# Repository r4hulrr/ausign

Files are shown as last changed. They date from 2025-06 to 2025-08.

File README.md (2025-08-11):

# AUSIGN – Real-Time Auslan Sign Language Interpreter

 **Breaking communication barriers** for the Australian Deaf community with an affordable, wearable, real-time Auslan-to-speech translation glove. Check out the [demo video](https://drive.google.com/file/d/1WPN_qFuqe7VqrdAuftsNLOaqI1UlMCOe/view?usp=sharing).

## Overview
**AUSIGN** is a wearable assistive technology device designed to translate **Australian Sign Language (Auslan)** into spoken English **in real time**, enabling smoother and more natural communication for deaf and non-verbal individuals.

Unlike existing ASL-centric devices, AUSIGN is **purpose-built for Auslan**, incorporating contextual awareness via a heart-rate sensor, low-latency audio feedback, and Bluetooth connectivity for flexible output through a mobile/desktop app.

##  Key Features
- **Auslan-specific design** – recognises grammar and gestures unique to Auslan.
- **Context-aware translation** – heartbeat sensing to infer emotional tone.
- **Low-latency output** – low latency translation for natural conversations.
- **Comfort & portability** – under 150 g, designed for all-day wear.
- **Cross-platform UI** – BLE-connected Python GUI.
- **Rechargeable & all-day battery life** – ~6 hours continuous operation.

## System Architecture

**High Level Diagram**

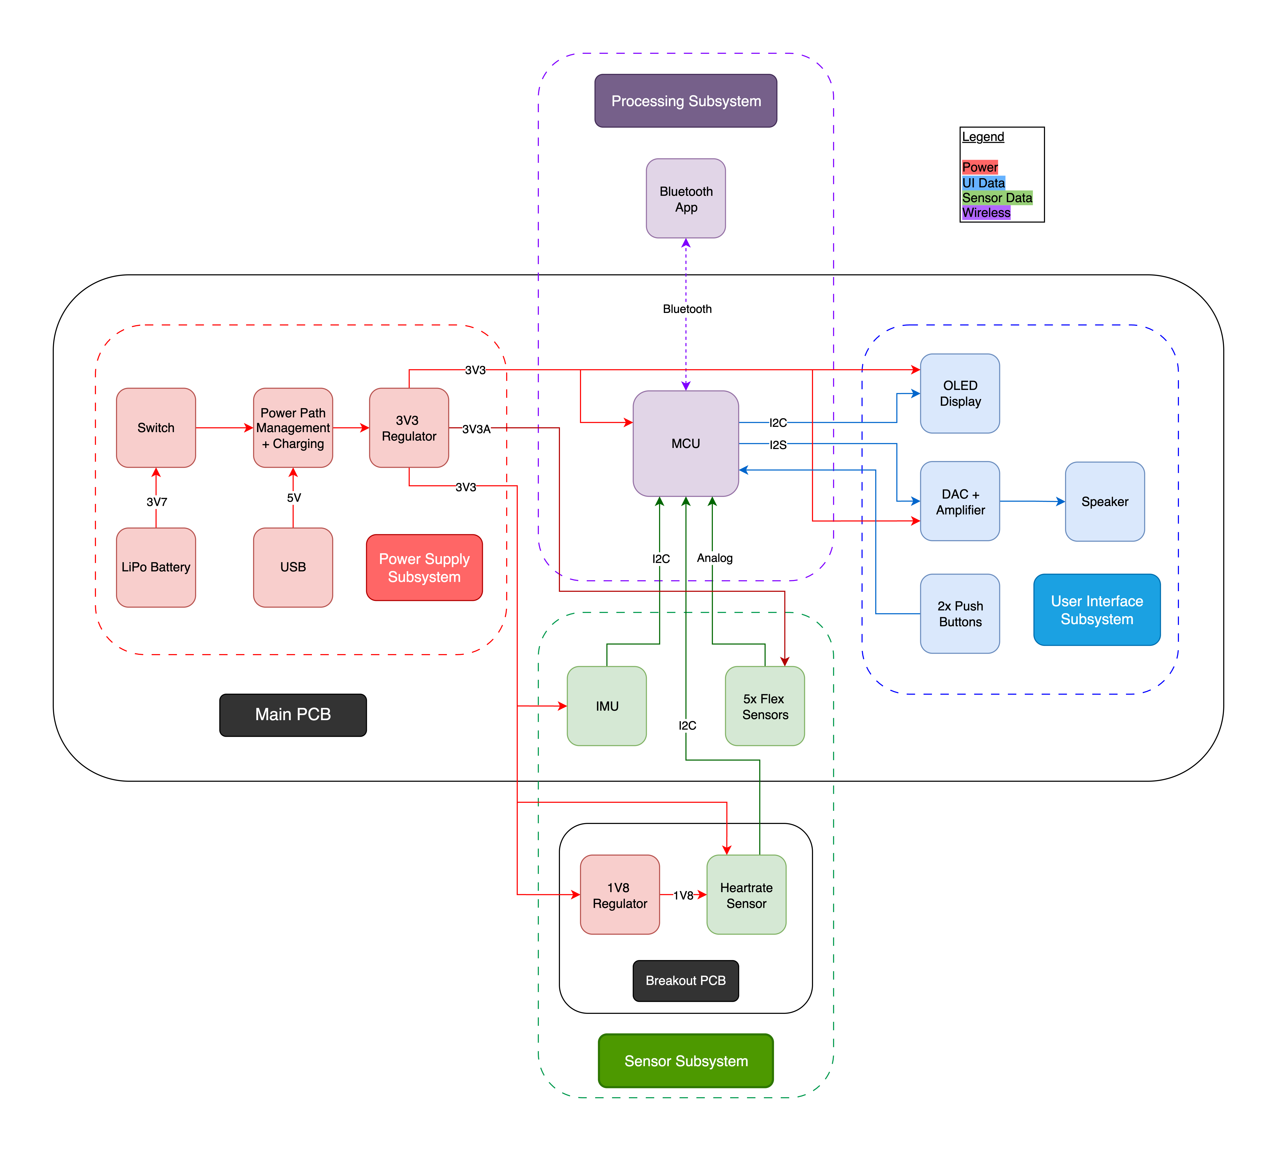
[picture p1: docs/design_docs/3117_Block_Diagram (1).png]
High Level Diagram


**Hardware**
- **Sensors:**  
  - 5× flex sensors for finger bend detection  
  - LSM6DSOTR 6-axis IMU for hand motion/orientation  
  - MAX30105 heartbeat sensor for emotional context  
- **Processing:** ESP32-S3 microcontroller with BLE & I²S audio output  
- **Output:** OLED display + speaker (via MAX98357A DAC/amp), 2× customisable push buttons  
- **Power:** 3.7 V Li-Po battery with BQ24074 power management & charging

**Software**
- **Firmware:** Reads sensor data, sends via BLE to host app, plays audio from internal flash.  
- **Recognition algorithm:** Condition-matching engine using flex, IMU, and BPM thresholds from CSV definitions.  
- **GUI:** Python-based BLE interface for displaying recognised signs, sensor status, and audio playback.  

## Repository Structure
```
├── firmware/ # ESP32-S3 C++ firmware (Arduino/ESP-IDF)
│ ├── src # Contains the main esp32 code along with test code for every component
│ ├── partitions # Custom partition implemented for our 16MB Flash size
├── gui/ # Python BLE GUI application
│ ├── frontend.py # main GUI script
│ ├── signs.csv # Sign definition mappings
│ └── ...
├── hardware/ # PCB schematics and board layouts
│ ├── main_board/
│ ├── breakout_board/
├── demo # Demo video
│ ├── demo_video.mp4
├── docs/ # design docs
└── LICENSE
└── README.md
```

## Demo
Check out the [demo video](demo/demo_video.mov) to see AUSIGN in action.

## License
This project is licensed under the [MIT License](LICENSE).

## Authors
- **Rahul Ramachandran** 
- **Enzo Moriguchi** 

---
> *“Technology is best when it brings people together.”* – AUSIGN aims to bridge the communication gap and foster inclusion through engineering innovation.

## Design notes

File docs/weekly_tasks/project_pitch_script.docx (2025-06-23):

Slide 2 – Introduction & Needs Assessment

The Problem
Deaf and non-verbal Australians often lack affordable, real-time ways to communicate without an interpreter. Auslan support in existing devices is nearly absent.

Limitations of Current Solutions

- Expensive (e.g. Brightsign glove ≈ $6,800 AUD)
- Mostly support ASL, not Auslan
- Require phones/internet, lack context awareness

User Needs

- Real-time Auslan-to-speech
- Portable, offline, affordable
- Emotion/context inference
- Intuitive, day-long use

🔷 Slide 3 – Market Analysis

User Validation (21 Respondents)

- 67% currently use aids
- Avg usefulness: 6.1/10
- Openness to new devices: 8.2/10
- 62% interested in AUSIGN

Market Opportunity

- 16,000 Auslan users (2021 Census)
- 3.6M Australians with hearing loss → 7.8M by 2060
- Interpreter costs ≈ $127.50/hr
- Existing solutions out of stock, ASL-only

Target: Auslan users aged 25–59 needing daily, affordable communication tools

🔷 Slide 4 – Key Requirements

- ≤ 50g per glove
- ≥ 12 hours battery life
- ≥ 90% translation accuracy
- ≤ 2 seconds latency
- Offline functionality
- Under $100 manufacturing cost
- Customizable settings (volume, dialect)
- Emergency signal support

🔷 Slide 5 – Product and Design Concepts

Product Concept
AUSIGN is a wearable glove that captures Auslan gestures and translates them to spoken English via onboard or phone-based audio.

Design Highlights

- Flex sensors + IMU = accurate gesture detection
- Heartbeat sensor = emotional context
- ESP32 = processing + Bluetooth for personalization
- Onboard speaker + optional LCD feedback
- Custom mapping of signs
- Emergency button (e.g., “Help”)

🔷 Slide 6 – Unique Selling Points

1. Auslan-specific – Not ASL-focused like competitors
2. Context-aware – Heart rate input for emotion detection
3. Gesture + Motion Fusion – Flex + IMU improves accuracy
4. Lightweight & Comfortable – Under 50g
5. Bluetooth-Enabled – Mobile app for personalization
6. Offline Support – Usable without internet
7. Custom Sign Training – Adaptable to regions/users
8. Affordable – Sub-$100 vs $6,800 competition

🔷 Slide 7 – High-Level Block Diagram

Use your Week 3 block diagramshowing:

Subsystems:

- Input: Flex sensors, IMU, Heartbeat, Button
- Processing: ESP32
- Output: Speaker, LCD
- Power: LiPo battery, TP4056, Boost Converter
- Communication: Bluetooth to App

Label clearly: arrows showing data flow, highlight modularity and context handling.

🔷 Slide 8 – Technical Components

Subsystem | Component | Notes
MCU | ESP32-WROOM-32 | I2C, UART, ADC, Bluetooth
Finger Sensor | 3” Flex Sensors | 25k–100kΩ resistance range
Motion Sensor | MPU6050 IMU | 6-axis detection
Biometric Sensor | MAX30102 | Heart rate & oximeter
Output | 3W Speaker, 20×4 LCD | Compact + intuitive UI
Power | TP4056 + LiPo + MT3608 | USB charging + 5V boost
Input | Tactile Push Button | Emergency signal

🔷 Slide 9 – Financial Plan

Per Unit Manufacturing Estimate

- ESP32: $8
- Flex Sensors ×5: $20
- MPU6050: $5
- MAX30102: $6
- Speaker + Amp: $4
- LCD: $7
- Power Circuit (TP4056 + MT3608): $3
- Misc (PCB, Glove Material, Button): $15 → Total: ~$68 AUD

Selling Price: $150–200 AUD
NPV: Viable pricing based on competitor comparison
Profit Margin: ≥ 100%, with accessibility focus

🔷 Slide 10 – Development Plan (Wk 6–10)

Week 6–7

- Hardware Integration (Flex + IMU + HR + Speaker)
- Sensor Calibration

Week 8

- Real-time Auslan-to-Speech Mapping
- Bluetooth App UI + Emergency Button Logic

Week 9

- Context Awareness Logic (Heart rate threshold)
- Output testing with user trials

Week 10

- Final Testing + Demo
- User Feedback + Iteration
- Presentation and Documentation

Team Allocation:

- Hardware: [Name]
- Firmware + ML Model: [Name]
- App + UI: [Name]
- Integration & Testing: All

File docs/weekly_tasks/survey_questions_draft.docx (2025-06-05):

# AUSIGN - An AUSLAN Interpreter

The primary concept behind AUSIGN is to design a pair of smart gloves that interpret Auslan (Australian Sign Language) and convert the signs into spoken language via built-in speakers. This will empower individuals who are deaf or nonverbal to communicate more easily with the broader public, particularly in situations where an interpreter is not available.

One of our key design goals is to make the gloves lightweight, portable, and comfortable, but we also understand that usability involves more than just hardware specs. To ensure that AUSIGN addresses real user needs, we are conducting primary market research through a structured survey. This will help us:

- Validate the real-world usefulness of our concept
- Gather direct feedback on desirable features, comfort, pricing, and expectations
- Understand attitudes within the Deaf and non-verbal community toward current assistive technologies

In order to gather meaningful and relevant insights, we plan to distribute this survey to individuals who are deaf, hard of hearing, or non-verbal, as well as people who work closely with them (e.g. Auslan interpreters, educators, and disability support workers). Specifically, we will target local Deaf advocacy and community groups along with online forums and Reddit communities (e.g. r/auslan, r/deaf).

Keeping this in mind, we came up with around 10 questions that we feel would help us best understand the market. We distributed them to the above mentioned groups through online forms to the best of our ability. We also got our relatives and anyone they knew who had a hearing impairment to fill out our form in order to get more data. In total, we received about 21 responses. The questions and the results are as follows:

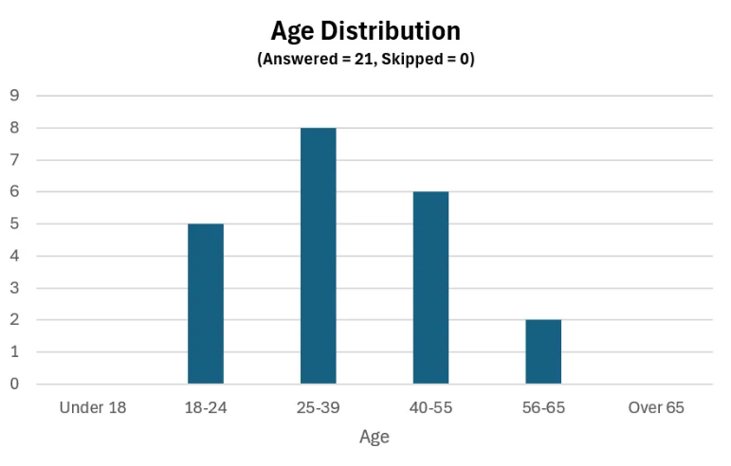
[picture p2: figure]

Section 1: Demographics

1. Age:
  a. Under 18
  b. 18 - 24
  c. 25 - 39
  d. 40 - 55
  e. 56 – 65
  f. Over 65
2. What is your level of hearing loss?

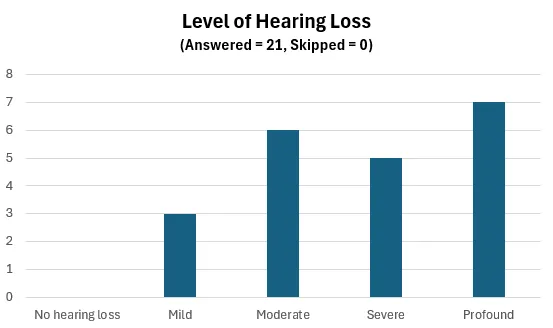
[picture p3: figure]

  a. No hearing loss
  b. Mild (21 - 40dB)
  c. Moderate (41 - 70dB)
  d. Severe (71 - 90dB)
  e. Profound (91+ dB)
3. Are you also non-verbal or do you experience speech difficulties?

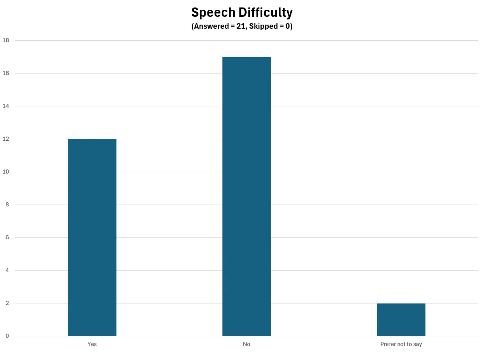
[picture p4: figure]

  a. Yes
  b. No
  c. Prefer not to say

Section 2: Communication Tools and Tech Usage

4. Do you currently use any assistive devices for communication?

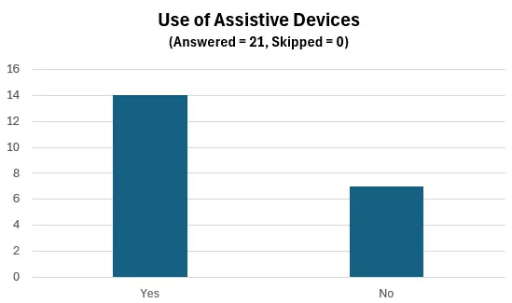
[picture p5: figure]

  a) Yes
  b) No
5. (If answered Yes above)

What communication device(s) do you currently use?

(Open-ended)

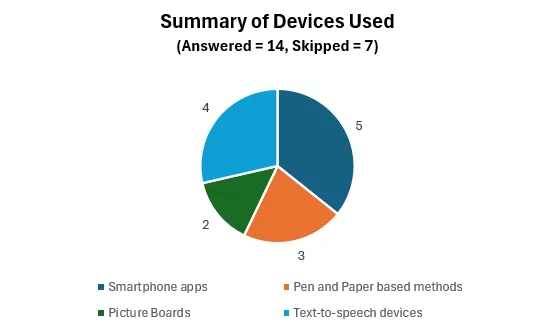
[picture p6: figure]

6. (If answered Yes above)

On a scale of 1 to 10, how useful is your current communication aid in daily life?

(1 = Not useful at all, 10 = Extremely useful)

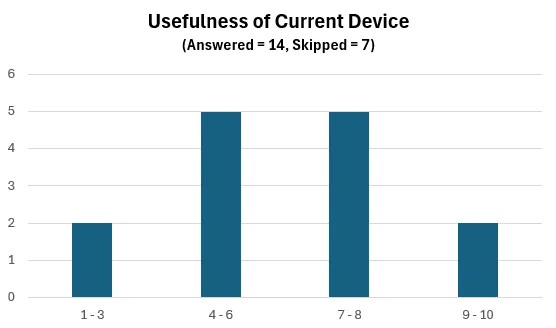
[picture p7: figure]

7. (If answered No to Q4)

How open are you to using a new device that may improve daily communication?

(1 = Not open at all, 10 = Very open)

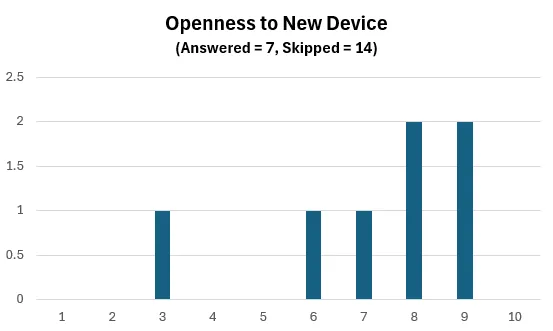
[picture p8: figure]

Section 3: Product-Specific Feedback

8. Would you be interested in using a device like AUSIGN that converts Auslan gestures to speech? If no, why?

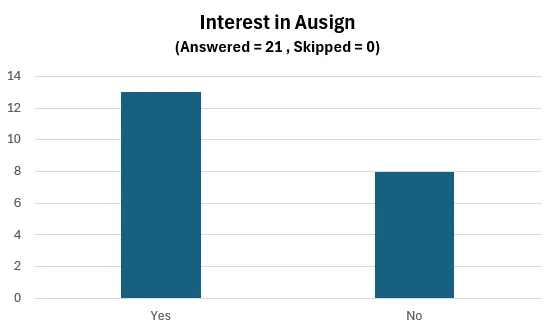
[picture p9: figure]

(Primary reasons for not interested deviate towards concerns about feasibility of complete interpretation of Auslan as it relies on facial expressions and context. There were also concerns about regional sign variation.)

9. Aside from translating sign language into speech, are there any additional features you believe would make this product more useful or appealing for members of the Deaf or non-verbal community?

(Most features fall under context awareness, ease of use, long battery file and comfortability)

10. What price range would you consider reasonable for this product?

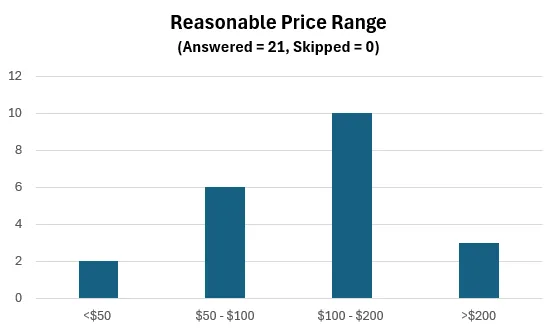
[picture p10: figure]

  a. Less than 50 AUD
  b. 50 to 100 AUD
  c. 100 to 200 AUD
  d. Over 200 AUD

Survey Outcomes

As mentioned before, our survey gathered input from 21 respondents within the Deaf and non-verbal community. Most were aged 25–55 with moderate to profound hearing loss, confirming a mature and tech-aware user base. Around 67% currently use communication aids—mostly smartphones or text-to-speech devices—with an average usefulness rating of 6.1/10, suggesting scope for improvement. Non-users reported a high openness to trying new tools (average 8.2/10), validating demand for improved solutions.

62% expressed interest in AUSIGN, but 38% raised concerns based on past devices that failed to capture Auslan’s full complexity (e.g. facial cues, grammar, regional signs). Using ML to achieve context awareness and having a larger data set could help with this issue as it seemed to be a major point of concern among many. Most respondents supported a $100–200 AUD price range. These findings will guide AUSIGN’s design focus on usability, adaptability, and affordability.

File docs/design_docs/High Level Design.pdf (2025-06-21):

# AUSIGN - An AUSLAN Interpreter

### Product Functions (Summary List)

1. Detect finger bending positions (sign gestures)
2. Detect hand orientation and motion (gesture context)
3. Detect emergency signals via a panic button
4. Measure heart rate for emotional context
5. Convert gestures into audio messages
6. Display information to the user (feedback)
7. Transmit sensor data wirelessly to a host system (e.g., smartphone)
8. Provide power to the entire glove system

# High-Level Block Diagram

AUSIGN | - An AUSLAN Interpreter | 1

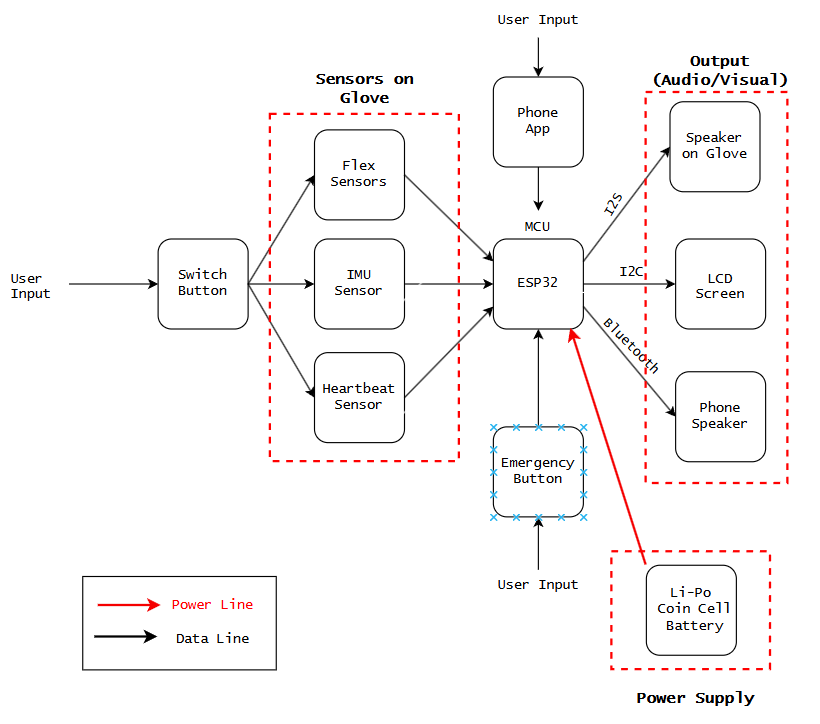
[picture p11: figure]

# Technical Components

### 1. Microcontroller Unit – ESP32-WROOM-32

Manufacturer: Espressif Systems

Justification:

Integrated Bluetooth and Wi-Fi for communication
Rich peripheral set (ADC, I2C, UART, PWM) enables interfacing all sensors without external chips

3.3V operation matches sensor logic levels
Dev board form factor suitable for breadboarding and prototyping

Extensive community support and low cost

### 2. Flex Sensors – 3" 25kΩ-100kΩ variable resistance

Manufacturer: Adafruit

Justification:

Widely used, robust component specifically designed for detecting single-axis bending, perfect for finger gesture recognition.
Resistance changes from ~25kΩ (flat) to ~100kΩ (fully bent), easily measurable using a voltage divider circuit with ESP32's ADC.

Readily available

### 3. IMU Sensor – MPU6050

Justification:

Integrates 3-axis accelerometer and gyroscope
I2C interface supported directly by ESP32

Compact and well-documented, with sample code and libraries Low power consumption, ideal for wearables

### 4. Heartbeat Sensor – MAX30102

Manufacturer: TZT
Justification:

Optical pulse oximeter and heart-rate sensor in one package Integrated LED driver and ADC simplifies design

I2C communication and low power use align well with ESP32

### 5. Speaker – Mini Speaker 3W, 4Ω, 4cm diameter

Manufacturer: YTDMEN

Justification:
Compact and lightweight for glove mounting

Suitable for low-power PWM/I2S audio output from ESP32 Easily driven with audio amplifier if needed

### 6. Emergency Push Button - Mini Push Button Switch

Manufacturer: Sparkfun

Justification:

Simple digital input to MCU with internal pull-up/down Small tactile form factor suitable for glove

### 7. LCD Display – Freenove I2C 20x4 LCD Module

Manufacturer: Freenove

Justification:

Low power I2C interface with ESP32
Provides clear user feedback in compact form

Widely supported libraries for display text and icons Reasonably priced and readily available

### 8. Power Module – TP4056 + 3.7V LiPo Battery + Boost Converter (MT3608)

Justification:
TP4056 for USB charging and battery protection

LiPo battery offers lightweight portable power
MT3608 boost converter supplies stable 5V to speaker and peripherals as needed

Cost-effective and widely available modules

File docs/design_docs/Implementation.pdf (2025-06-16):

# Implementation

The first part to implement will be the flex sensors. These are essentially variable resistors (like potentiometers). As seen in the datasheet below, the resistance varies between 5 kΩ and 10 kΩ. I will connect the flex sensor in series with a
3.3 kΩ resistor to 3.3 V (VCC), and use the midpoint between the two resistors as the input to the ADC.
This forms a basic voltage divider. Theoretically:
Minimum ADC voltage (when flex = | 10 kΩ):
Maximum ADC voltage (when flex = | 5 kΩ):Vout=5+105×3.3=1.1 V

So the voltage range at the ADC will be 1.98 V to 2.48 V, depending on the bend angle.

Vout = 10+3.3 ×

10 3.3 = 2.48V

Vout = 5+3.3 ×

5 | 3.3 = 1.98V

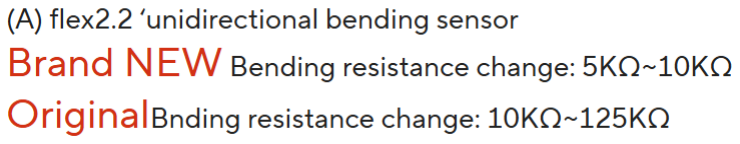
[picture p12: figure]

Implementation | 1

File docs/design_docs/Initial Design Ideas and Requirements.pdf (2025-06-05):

# AUSIGN - An AUSLAN Interpreter

# Needs Assessment

Who are you designing the product for? What is your target audience? People who have hearing and/or speech impairment, and use sign language to communicate. Targeting the Australian community specifically.

Why do they need it?
From our market research, we can see that a good percentage of Australians with hearing and/or speech impairment feel ostracized from society due to not being able to properly communicate with the wider public. There is a lot more research/projects targeting ASL (American Sign Language) but very little for AUSIGN, leaving them in the dust.

What do they need?
Again looking at our primary and secondary market research, there is a lack of a sure front and easy way for our target audience to communicate with the larger public. A lot of them use smartphone apps/ text-to-speech devices but are not satisfied with the current scope of technology available to them. They are skeptical of previous products as they do not take into account the context issues associated with it. E.g. The word for “chair” could mean “sit” depending on context. They also prioritize portability and ease of use.

Where and how will it used?
Ideally, we would like to incorporate a device with extended battery life, allowing our target audience to use the device throughout the day, as this product would be of the utmost importance during emergencies, which we cannot predict. It will
AUSIGN | - An AUSLAN Interpreter | 1

be available as easy to wear gloves and will convert their hand movements into audio through a speaker attached on the glove.

What features do they need in it?

Long battery life
Portable and lightweight

Ease of use with a easy to access button to turn on/off the gloves
Strong and solid UI to adjust the gloves based on personal preferences (e.g. volume, special signals etc)

Large database of signs with context awareness

What are the issues/limitations of existing products/solutions?
As mentioned before, most devices are based on ASL with little to no support for AUSLAN. They also lack context awareness which severely limit the usage of these devices as it could be very different to traditional sign language. Also fail to recognize facial expressions as they affect what the sign could mean (e.g. signs with a tensed look on face could be associated with more strong meanings which the products in the market fail to identify)

# Requirements Analysis

Lightweight - This is a strong requirement among most of our respondents. Light cotton gloves weigh around 15-30 grams per glove; winter-fleeced gloves weigh around 40-60 grams per glove and mechanics/work gloves can weigh up to 100 grams per glove. We want our users to be comfortable so would want to keep our gloves weight to around 50 grams per glove.

Long battery life - Another strong requirement. Should last at least a full day of charge.
Durable - Would not want to keep replacing gloves

High accuracy - Would want it to be highly accurate with a large database of signs with context awareness

# Problem Statement

Deaf and non-verbal individuals in Australia need an effective, real-time communication tool because current solutions—such as text-to-speech apps and sign language gloves—fail to interpret the full complexity of Auslan, often lacking contextual awareness, facial expression recognition, and support for regional variation. This communication barrier limits independence and inclusivity in everyday social, professional, and emergency situations.

# Product Concept

AUSIGN is a wearable communication aid designed to empower deaf and non-verbal individuals by translating Auslan (Australian Sign Language) gestures into spoken language. It aims to reduce communication barriers in everyday settings such as public transport, workplaces, retail, and healthcare. By doing so, it helps users engage more independently with the broader community without needing an interpreter present.
The product is intended to be lightweight, comfortable, and easy to use throughout the day. It will support user-specific preferences and context-aware communication to make interactions feel more natural and intuitive. AUSIGN directly addresses the unmet needs identified through our user research, especially around portability, reliability, and the lack of Auslan-specific solutions in existing products.

# Design Concept

AUSIGN will consist of pair of light gloves with flex sensors along the fingers to detect stretching/folding of fingers. An Inertial Measurement Unit will be placed along the wrist. This combines an accelerometer (to measure linear motion), gyroscope (to measure rotational motion) and potentially a magnetometer (to measure orientation). These two can be combined to help us understand the hand movements made by the user in sufficient detail. The values from this sensor will be fed into an ESP32, which will process these signals and drive the audio output on the speaker attached to the glove.
To enhance context-awareness, a heartbeat sensor will be incorporated into the glove system. By monitoring the user’s physiological state (e.g. elevated heart rate during stress), the device can infer emotional tone or urgency behind signs. This serves as a partial substitute for facial expressions and body language, which are key components of Auslan communication but difficult to capture with sensors alone.
An ESP32 is chosen as it has Bluetooth capabilities which would allow us to make a frontend app to enhance user experience and modify certain settings such as voice output volume, gesture sensitivity, preferred Auslan dialect, and custom sign mappings to their particular needs.
We will use a 3.7V 800mAh Li-Po battery as this is lightweight, rechargeable with a good energy density allowing for a long battery life. An easy to use button should also be included to turn on/off the gloves and also for emergency situations(e.g. to shout ‘help’ in case of emergency - this would be user customizable).

# Unique Selling Points

1. First Auslan-Focused Wearable Translator
Unlike most sign-to-speech devices built for American Sign Language (ASL), AUSIGN is designed specifically for Auslan, addressing regional sign variations and grammar unique to the Australian Deaf community.
2. Context-Aware Translation Using Biometrics
AUSIGN uses a heartbeat sensor to infer emotional tone (e.g. urgency or stress), adding contextual awareness that conventional gloves lack.
3. Gesture + Motion Fusion for High Accuracy
Combines flex sensors on fingers with a wrist-mounted IMU (inertial measurement unit) to recognize both static hand shapes and dynamic gestures, improving recognition accuracy for complex Auslan signs.
4. Lightweight and Comfortable Design

Designed to weigh under 50g per glove, AUSIGN prioritizes long-term comfort for daily use, exceeding the wearability of most commercial smart gloves.

5. Bluetooth-Enabled Personalization App
Built on the ESP32, AUSIGN supports wireless communication with a companion mobile app, allowing users to adjust settings like voice output, gesture sensitivity, and dialect preference.
6. Custom Sign Mapping and User Training
Allows users to add personal or region-specific signs and train the system to recognize them, increasing inclusivity for diverse signers.
7. All-Day Battery Life with USB Charging
Powered by a 3.7V Li-Po battery optimized for energy-efficient use, the gloves can run for a full day and recharge via standard USB.
8. Voice Output Through Onboard or Phone Speaker
Offers both onboard audio output and phone-based speech relay, giving users flexibility based on environment and preference.

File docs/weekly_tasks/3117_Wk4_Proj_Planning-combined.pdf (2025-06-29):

# Week 4 Project Planning Task

## Task 1: Initial Estimate of Manufacturing Costs

Category | Item | Part Number | Source | Unit Price (AUD) | Quantity | Total Cost (AUD)
Components | MCU | ESP32-WROOM-32E | DigiKey | $7.75 | 1 | $7.75
| Battery | 3.7V LiPo Battery | Amazon | $27.00 | 1 | $27.00
| BMS | BQ24075 | DigiKey | $3.43 | 1 | $3.43
| IMU | LSM6DSOTR | DigiKey | $6.12 | 1 | $6.12
| Flex Sensors | FS-L-0055-253-ST | DigiKey | $12.73 | 5 | $63.65
| Heartbeat Sensor | MAX30207CLB +T | DigiKey | $5.69 | 1 | $5.69
| LCD Screen | MD21605G12W 3-BNMLW-VE | DigiKey | $7.34 | 1 | $7.34
| Speaker | K 23 - 8 OHM | DigiKey | $7.54 | 1 | $7.54
| Push Buttons | EVQ-P7C01P | DigiKey | $0.48 | 2 | $0.96
| Wires | - | DigiKey | ~0.20 | ~10 | ~$2.00
| Passives (Resistors & Capacitors) | - | DigiKey | ~$0.15 | ~30 | ~$4.50
| Gloves | Safe Work Gloves | Amazon | $5.00 | 2 | $10.00
Shipping | DigiKey | - | DigiKey | - | 1 | -
| Amazon | - | Amazon | - | 1 | -
| JLCPCB | - | JLCPCB | $27.51 | 1 | $27.51
Manufacturing | PCB | - | JLCPCB | $3.06 | 1 | $3.06
| Labour | - | - | $47.70/hour | 160 | $ 7632
| Equipment | - | - | $100 | 1 | $100
| Marketing | - | - | $100 | 1 | $100
| Overheads | - | - | $50 | 1 | $50
Total | - | - | - | - | - | $8052.05

### Shipping: - Amazon offers free shipping - DigiKey offers free shipping for orders > $100 AUD which is the case here

### Manufacturing: - PCB cost is for 5x PCBs as per minimum order requirements on JLCPCB - Labour hourly rate is based on average hourly wages for a Junior Engineer, according

### to Indeed. The number of hours is based on an estimate of 2x people working for 8x

hours per week for 10 weeks.

### - Equipment, Marketing and Overheads costs are all estimates

### Estimate of Potential Profitability

Discount Factor P/A | 10%
Year | 0 | 1 | 2 | 3 | 4
Cost | 8052.05 | 7500 | 7500 | 7500 | 7500
Revenue | 0 | 50000 | 60000 | 70000 | 80000
Future Value | | 42500 | 52500 | 62500 | 72500
Present value | -8052.05 | 38636.36 | 43388.43 | 46957.18 | 49518.48
NPV | 170448.39

## Task 2: Work Breakdown Structure

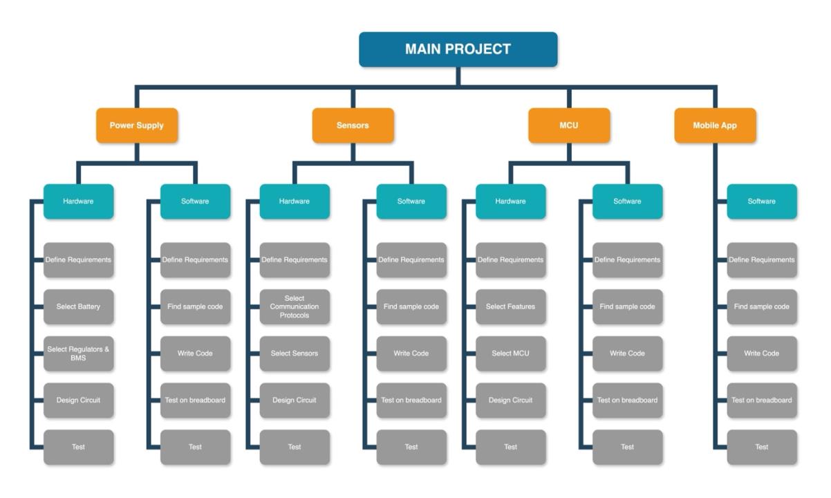
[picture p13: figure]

### Figure 1: Work Breakdown Structure

## Task 3: Gantt Chart

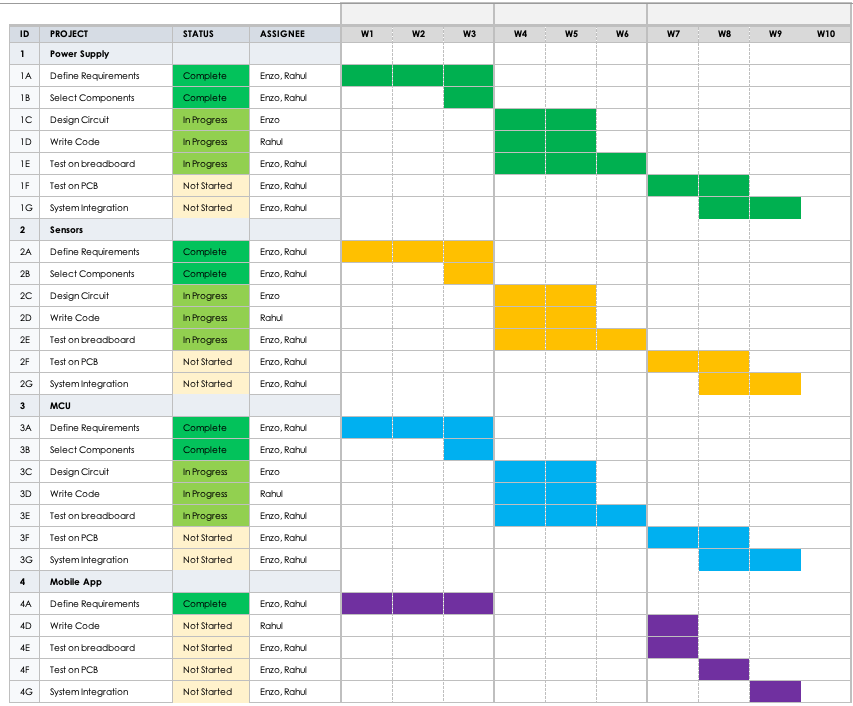
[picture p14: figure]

### Figure 2: Gantt Chart

## Task 4: Risk Assessment

Risk | Likelihood Impact | of Risk | Severity | Mitigation Strategy | Contingency Action
Sensor Signal Noise | Medium | High | High | Use low-pass filters and shielded cables; isolate analog and digital signals on PCB layout. | Re-route signal traces and add hardware filters. Use digital filtering fallback.
Poor Gesture Recognition Accuracy | High | High | High | Test with diverse gesture datasets; apply ML techniques or adaptive thresholds. | Retrain system with simplified gesture sets or manual tuning for reliable accuracy.
Microcontroller Memory Overflow | Low | Medium | Medium | Optimize firmware to store only essential variables; use memory-efficient data types. | Trim features in firmware or upgrade to MCU with higher memory if feasible.
Loose Wiring or Faulty Connections | Medium | High | High | Secure solder joints; use locking connectors and strain relief mechanisms. | Rewire or re-solder faulty joints. Replace cables/connectors and reverify.
Risk | Likelihood Impact | of Risk | Severity | Mitigation Strategy | Contingency Action
Low Market Adoption | Low | Medium | Medium | Engage with Auslan community early for feedback; showcase use cases to drive interest. | Pivot design for educational use or accessibility demos. Explore university partnerships.
Risk | Likelihood Impact | of Risk | Severity | Mitigation Strategy | Contingency Action
Missed Deadlines | Medium | High | High | Use a detailed Gantt chart; assign task owners and track weekly progress with buffer periods. | Rescope project: deprioritize low-impact features. Use weekend/makeup sprint.
Team Communication Gaps | Medium | Medium | Medium | Set weekly standups and shared task boards; ensure everyone is aligned. | Escalate blockers early. Allocate a group lead to facilitate communication.
Risk | Likelihood Impact | of Risk | Severity | Mitigation Strategy | Contingency Action
| High | Medium | Low
Battery Short Circuit or Overheating | Low | High | Medium | Add thermal cutoff and fuse. Use tested commercial battery pack with protection circuit. | Shut off glove immediately; switch to USB power for further debugging.

Technical

Business

Project Management

Safety

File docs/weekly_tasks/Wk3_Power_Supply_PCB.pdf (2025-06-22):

## Power Supply Design Assignment

Requirements

Parameter | Value
Input Voltage | 12V
Output Voltage | 3.3V
Output Current (max) | 500mA
Allowed Ripple | <100mV
Transient voltage deviation | +/-150mV
PCB Dimensions | 48mm x 48mm
I/O Connector | 2.54mm pitch header pins
Regulator IC: MC34063ECN
This regulator was chosen from the available options due to its THT nature for ease of soldering and is a very common component that has been widely used. Parameters such as max switch current and input voltage range were largely identical across the options and thus, did not influence the selection.
Calculations & Component Justification
The following calculations are primarily based on the equations provided in the MC34603ECN datasheet.
Feeback Resistors:
V_out = 1.25*(1+R2/R1) = 3.3V
R2 = 16.2kohm
R1 = 10kohm
V_out = 3.275V
These resistor values are standard values which give an output voltage that is within reason to the desired output voltage.
f = 50kHz, T = 1/f = 20us
A switching frequency of 50kHz was chosen as the maximum frequency of the IC is 100kHz and this value is within the safe operating range. This value also provides a good balance between minimising output ripple and avoiding greater switching losses.
Duty Cycle: D = 3.3V/12V = 0.275
t_on = D*T = 5.5us
t_off = (1-D)*T = 14.5us
Timing capacitor: C_T = 4.5*10^-5*t_on = 247.5pF = ~240pF
The value of 240pF as this is a standard value and is reasonably close to the calculated value such that it won’t affect the switching frequency of the IC.

I_PK(switch) = 2*I_out(max) = 2*500mA = 1A
R_SC = 0.3/ I_PK(switch) = 0.3/1 = 0.3ohm
Output capacitor: C_out = (I_PK(switch)*T)/(8*V_ripple) = (1*20u)/(8*100m) = 25uF =~22uF
This output capacitor value was chosen as it is a standard value and close to the calculated value.
Inductor (min): L_min = (V_in(min) – V_sat – V_out)/I_PK(switch)*t_on = (12-1.3-3.3)/1*5.5*10^-6 = 40.7uH = ~220uH
The equation provides the minimum inductor value which is required for the peak current to not exceed its requirement. However, a larger inductor provides a safe margin, reduces the output voltage ripple and improves performance during transients on the load. Thus, although the 82uH inductor may be adequate, the 220uH is more suitable and thus, was selected. Furthermore, the THT component of the inductor was selected due to the ease of soldering and changing out to the 82uH inductor if necessary or to compare their effects.

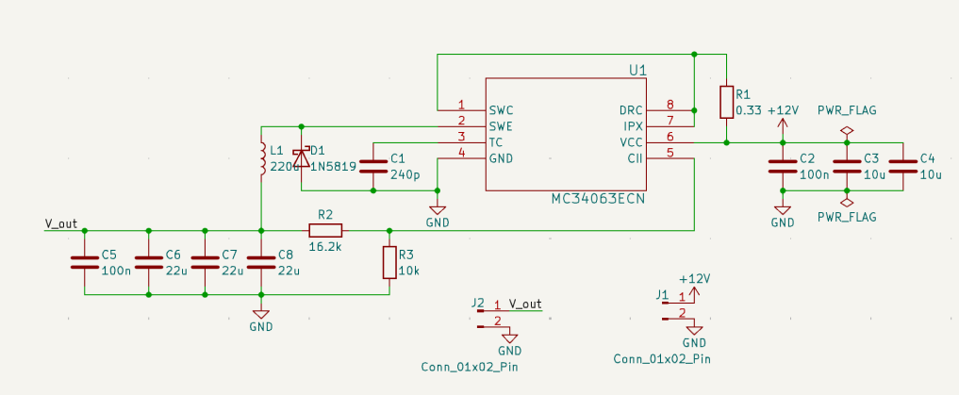
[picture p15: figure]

Figure 1: Schematic
Figure 1 above displays the schematic of the power supply design. It features all the components calculated earlier. The 1N5819 Schottky diode was chosen due to its low forward voltage drop, rating for 1A continuous and fast switching. This diode provides the discharge path for the inductor during the ‘OFF’ switching phase.
Input capacitor values of 100nF and 10uF were selected as the 100nF filters high frequency noise and the 10uF acts as a bulk energy storage. The output capacitor values of 100nF and 22uF were selected as the 100nF also filters out the switching and high frequency noise and the 22uF is from the calculations and is to supress the inductor output ripple. The schematic also features excess input and output capacitors which only the footprints will be placed to allow for optimisation during testing and provide no downside to the function of the design. These can be used to improve the output voltage ripple by increasing capacitance and reducing the equivalent series resistance (ESR), if needed.
All resistors and capacitors were chosen to be SMD, 0805 values with all capacitors being ceramic. The 0805 size was chosen as this is a common value that is large enough to hand solder if needed, particularly if capacitors need to be added or removed during testing. Furthermore, having all 0805 components allows for compatibility across different capacitor values.
Layout Justification

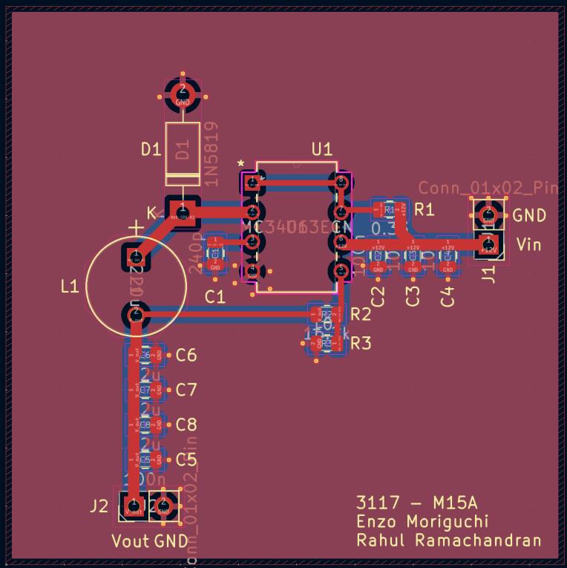
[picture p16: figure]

Figure 2: Layout
Figure 2 above displays the layout of the power supply, which features a 2-layer board with ground planes on both sides, stitched with vias close to all GND pads to provide low impedance return paths. All traces are kept short and direct, with 1mm width traces used for power traces to handle the higher currents and reduce resistive losses. 0.5mm traces were used for all other traces as they carry much less current.
On the input side, the 100nF input capacitor is placed closest to the IC to filter high frequencies with the larger 10uF capacitors placed close by for stabilising the input voltage. Similarly, the output capacitors are placed as close as possible to the output to filter out noise and smooth the voltage. The capacitors are placed slightly apart, not as close as possible, to allow for ease of modifications during testing as previously mentioned. This will allow for soldering or desoldering of single capacitors without affecting nearby capacitors.
The inductor and diodes are placed close to the output pin of the IC to minimise the loop area that can be formed from these components in conjunction with the output capacitors.
It should also be noted that although it is common practice to avoid 90-degree traces, the ones used here through the THT pins have little to no impact on the performance of the power supply, only to simplify routing, and given that this is not a high-speed design, with a low frequency (50kHz) used.

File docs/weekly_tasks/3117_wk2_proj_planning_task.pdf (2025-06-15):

# AUSIGN - An AUSLAN Interpreter

## Needs Assessment

Who are you designing the product for? What is your target audience?
We are designing this product predominantly for people who have hearing and/or speech impairment and use sign language to communicate. Of the many people around the world who use sign language, our target audience is the Australian community who use Auslan, the Australian sign language.
Why do they need it?
Our target audience of Auslan users need our product due to the lack of availability and accessibility of existing solutions. From our market research, we found that a good percentage of Australians with hearing and/or speech impairment feel ostracized from society due to not being able to properly communicate with the wider public. There is significant research and projects targeting ASL, the American Sign Language, but very little for Auslan, leaving them in the dust. Furthermore, our product will provide a simple solution that allows users to maintain their independence and reduce costs, compared to the current primary solution of a dedicated Auslan interpreter. This will be particularly beneficial in situations such as emergencies, workplace, school and university, doctors, and social events.
What do they need?
The target audience needs a solution that is portable and easy to use with a low cost, a lot of Auslan users don’t have the luxury of affording an interpreter. Looking at our primary and secondary market research, there is a lack of a sure front and easy way for our target audience to communicate with the larger public. A lot of them use smartphone apps or text-to-speech devices but are not satisfied with the current scope of technology available to them. They are sceptical of previous products as they do not consider the context issues associated with it. E.g. The word for “chair” could mean “sit” depending on the context. They need a product that can reliably translate Auslan to spoken English in real time. The product needs to have a long battery life, with the ability to charge, as needs to last a whole day of use and be intuitive.
Where and how will it be used?
The product will be used anytime and anywhere, when the user is at home, or leaves their home, i.e. workplace, school, university, doctors, social hangouts, restaurants, etc. Any setting where the user needs to communicate Auslan to spoken English, this product can be used. It will be available as an easy to wear gloves and will convert their hand movements into audio through a speaker attached on the glove.
What features do they need in it?
Features that are required for this product include:
- Long battery life: for lasting all day and in case of emergencies which can occur at any time.
- Portable and lightweight: for ease of use and portability
- Simple user interface: easy to access button to turn on/off the gloves
- Customisable settings: for adjusting the gloves based on personal preferences (e.g. volume, special signals etc)
- Large database of signs with context awareness: to differentiate between two words based on context
- Offline functionality: for use without the need for network coverage
- Comfort and durability: for user satisfaction and product longevity
What are the issues/limitations of existing products/solutions?
As mentioned before, most devices are based on ASL with little to no support for Auslan. They also lack context awareness which severely limit the usage of these devices as it could be very different to traditional sign language. Also, existing solutions fail to recognize facial expressions as they affect what the sign could mean (e.g. signs with a tensed look on face could be associated with more strong meanings which the products in the market fail to identify). Cost is another factor as existing glove-based products are very expensive and typically sold out, making them very inaccessible.

## Requirements Analysis

Lightweight – Each glove must weigh no more than 50 grams
- This is a strong requirement among most of our respondents from the survey. Light cotton gloves weigh around 15-30 grams per glove; winter-fleeced gloves weigh around 40-60 grams per glove and mechanics/work gloves can weigh up to 100 grams per glove. We want our users to be comfortable so would want to keep our gloves weight to around 50 grams per glove.
Long battery life – System must function for a minimum of 12 hours of continuous use on a single charge
- Another strong requirement desired by respondents through the survey. They expect a reliable product for constant use throughout the day and in emergency situations which could occur at any given time, where charging might not be possible.

Durable – Each glove must withstand a minimum of 6 months of regular daily use without degrading.
- Survey respondents highlighted the need for a reliable and low-cost solution. Many users, particularly those with lower incomes won’t be able to afford to replace or repair the product frequently.
High accuracy – The product must correctly translate Auslan to spoken English with 90% accuracy
- Incorrect translations could lead to miscommunication. This would be critical in emergencies where users may need to quickly and accurately communication their situation to get the correct help they need. Survey respondents also highlighted that inaccuracies in existing solutions cause frustrations.
Low latency – The output speech must be within 2 seconds of the sign gesture completion
- A delay between the sign gesture and output audio can undermine natural conversation. It can also lead to confusion in the listener, particularly if the user is constantly gesturing signs.
Customisable – The product must allow to user to adjust output volume and speed, and conserve battery life
- Depending on the situation and environment, the user may need to be louder or quieter. A method to turn on or off the product is necessary to preserve battery life.
Offline functionality – The product must operate without network coverage
- Users may need to use the product where they don’t have access to internet or cannot afford constant internet access.
Cost effective – The product must cost under $100 AUD to manufacture
- Existing solutions are very expensive and those particularly with a low income, can’t access sufficient solutions. Survey respondents also expressed their need for a low-cost solution as they aren’t willing to spend over $200 at most.

## Problem Statement

Deaf and non-verbal people in Australia need an effective, real-time communication tool to translate Auslan to spoken English. Current solutions, such as text-to-speech apps and sign language gloves, fail to interpret the full complexity of Auslan, often lacking contextual awareness and facial expression recognition. Other solutions such as an interpreter are very costly and hard to obtain. This communication barrier limits independence and inclusivity in everyday social, professional, and emergency situations.

## Product Concept

AUSIGN is a wearable communication aid designed to empower deaf and nonverbal individuals by translating Auslan (Australian Sign Language) gestures into spoken English. It aims to reduce communication barriers in everyday settings such as public transport, workplaces, retail, and healthcare. By doing so, it helps users gain more independence within the broader community without needing an interpreter present. The product is intended to be lightweight, comfortable, and easy to use throughout the day. It will support user-specific preferences and context-aware communication to make interactions feel more natural and intuitive. AUSIGN directly addresses the unmet needs identified through our user research, especially around portability, reliability, and the lack of Auslan-specific solutions in existing products.

## Design Concept

AUSIGN will consist of pair of lightweight, durable gloves with flex sensors along the fingers to detect stretching or folding of fingers. An Inertial Measurement Unit (IMU) will be placed along the wrist. This combines an accelerometer (to measure linear motion), gyroscope (to measure rotational motion) and potentially a magnetometer (to measure orientation). These can be combined to help us understand the Auslan hand movements made by the user in sufficient detail. The values from these sensors will be fed into an ESP32 microcontroller, which will process these signals and convert them to spoken English to drive the audio output on the speaker attached to the glove.
To enhance context-awareness, a heartbeat sensor will be incorporated into the glove system. By monitoring the user’s physiological state (e.g. elevated heart rate during stress), the device can infer emotional tone or urgency behind signs. This serves as a partial substitute for facial expressions and body language, which are key components of Auslan communication but difficult to capture with sensors alone.
The ESP32 was chosen as it has Bluetooth capabilities which would allow us to make a frontend app to enhance user experience and modify certain settings such as voice output volume, gesture sensitivity, preferred Auslan dialect, and custom sign mappings to their needs.
We will use a 3.7V 800mAh Li-Po battery as this is lightweight, rechargeable with a good energy density allowing for a long battery life. An easy-to-use button will also be included to turn on/off the gloves and for emergency situations (e.g. to shout “help” in case of emergency, this would be user customizable).

## Unique Selling Points

1. First Auslan-focused wearable translator. Unlike most sign-to-speech devices built for American Sign Language (ASL), AUSIGN is designed specifically for Auslan, addressing regional sign variations and grammar, unique to the Australian Deaf community.
2. Context-aware translation using biometrics. AUSIGN uses a heartbeat sensor to infer emotional tone (e.g. urgency or stress), adding contextual awareness that conventional gloves lack.
3. Gesture + motion fusion for high accuracy. Combines flex sensors on fingers with a wrist-mounted IMU to recognize both static hand shapes and dynamic gestures, improving recognition accuracy for complex Auslan signs.
4. Lightweight and comfortable design. Designed to weigh under 50g per glove, AUSIGN prioritizes long-term comfort for daily use, exceeding the wearability of most commercial smart gloves.
5. Bluetooth-enabled personalization app. Built on the ESP32, AUSIGN supports wireless communication with a companion mobile app, allowing users to adjust settings like output volume, speed, gesture sensitivity, and dialect preference.
6. Custom sign mapping and user training. Allows users to add personal or region-specific signs and train the system to recognize them, increasing inclusivity for diverse signers.
7. All-day battery life with USB charging. Powered by a 3.7V Li-Po battery optimized for energy-efficient use, the gloves can run for a full day and recharge via standard USB.
8. Voice output through onboard or phone speaker. Offers both onboard audio output and phone-based speech relay, giving users flexibility based on environment and preference.

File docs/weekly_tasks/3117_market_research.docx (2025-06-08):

# Wk1 - Project Planning Activity

## Task 2 - Secondary Market Research

A sign language interpreter is a wearable device designed to help those who are deaf and hard of hearing to communicate easier with others.

### Market Size

The primary target market for the product is deaf, hard of hearing and mute people. According to the 2021 Australian Census, approximately 16,000 use Auslan, the Australian Sign Language (Deaf Connect, 2022). This number is a rise from approximately 5,300 users in 2001, indicating a clear increase in Auslan usage at home and is expected to continue to rise (Deaf Connect, 2022). Furthermore, according to the 2022 Australian Deaf Census, the majority of respondents were between the ages of 25 to 59 years, meaning that our primary target market would consist of those within this age range (Deaf Australia, 2023). According to the 2022 Australian Deaf Census, 1 in 3 students were offered no communication access options in secondary school, only 59% of those employed are provided with an in person Auslan interpreter by their employer, and only 1% of people have a GP who uses Auslan (Deaf Australia, 2023). These statistics clearly show the lack of accessibility that deaf, hard of hearing and mute people have in many critical aspects of life. Many people who need to use Auslan to communicate simply aren’t offered adequate services to help them or are unable to obtain them. Hourly rates for Auslan interpreting begin from $127.50, which some people simply cannot afford, particular those who may have low income or support. In Australia, there are about 3.6 million people with some form of hearing loss and the number is expected to double to 7.8 million by 2060 (Department of Health, Disability and Aging, 2024). Also, according to the Medical Services Advisory Committee, each year, more than 500 children are born with moderate to profound permanent childhood hearing impairment (MSAC, 2007). All this information strongly indicates the need and benefit of a sign language interpreter for young to pre-senior adults.

### Related Existing Products

Existing solutions for sign language interpreters typically fall under the categories of wearable devices or online websites or apps. The main competitor to our wearable sign language interpreter is a company called Brightsign. They produce a wearable glove called the Brightsign Glove which translates over 300 different sign languages into over 40 different languages, outputting to a wearable speaker or mobile app. This is the only commercially available wearable device on the market and although it is they present their strengths, there are a few issues with it. Firstly, the availability. The product is currently sold out with no indication of when they will be in stock again and doesn’t indicate whether Auslan is included or not. And secondly, the cost. The product costs 4,415 USD which is approximately 6,800 AUD, a very steep price point (Brightsign, 2025). Other competitors are mobile apps and websites such as SignAll which use an AI and computer vision through a mobile app and requires a phone and internet connection, however, there is a waitlist for it (SignAll, 2025). Or Signapse AI or DeepASL, however, most of these solutions typically only translate American Sign Language (ASL) and not Auslan.

All the above products have a common issue; it is not readily accessible in Australia to Auslan users. Mobile apps and online solutions also present the problem of requiring a mobile device and internet connection for the translation. Although most people in the target market would typically always carry a mobile phone with an internet connection, some people may not be able to afford mobile devices or suitable devices capable of running these applications, which must be accounted for. A wearable device which outputs to a speaker or LCD screen is a much more suitable option for the target market. Furthermore, a wearable device would be much more suitable in emergency wear the user needs to quickly communicate key information quickly, without the need to open and set up an mobile application. A product that is easily accessible in Australia for Auslan users is necessary to help those who are deaf, hard of hearing or mute to communicate to others through Auslan.

References

Australian Institute of Health and Welfare (2016). 3.15 Vision and hearing disorders | Australia’s Health 2016. [online] Available at: https://www.aihw.gov.au/getmedia/48ee92a8-d373-4354-8df2-d664a974034f/ah16-3-15-vision-hearing-disorders.pdf.aspx [Accessed 8 Jun. 2025].

Brightsign (2023). BrightSign Glove. [online] BrightSign. Available at: https://shop.brightsignglove.com/collections/frontpage/products/glove [Accessed 8 Jun. 2025].

Deaf Connect (2022). Auslan User Statistics | 2021 Census - Deaf Connect. [online] Deaf Connect. Available at: https://deafconnect.org.au/our-news/auslan-user-statistics-2021-census [Accessed 8 Jun. 2025].

Deaf Australia (2023). A Snapshot of Deaf People’s Experiences Briefing Paper. [online] Available at: https://deafaustralia.org.au/wp-content/uploads/2023/02/Deaf-Census-Snapshot.pdf [Accessed 8 Jun. 2025].

Health (2024). About ear health. [online] Australian Government Department of Health and Aged Care. Available at: https://www.health.gov.au/topics/ear-health/about [Accessed 8 Jun. 2025].

MSAC (Medical Services Advisory Committee) (2007). National performance indicators for neonatal hearing screening in Australia. [online] Available at: https://www.aihw.gov.au/getmedia/8df964e6-e1ff-469e-b350-846e82e74c15/15996.pdf.aspx?inline=true [Accessed 8 Jun. 2025].

SignAll (2024). SignAll Sign Language Translation App. [online] Signall.world. Available at: https://signall.world/ [Accessed 8 Jun. 2025].

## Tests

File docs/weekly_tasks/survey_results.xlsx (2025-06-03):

Question | Answered | Skipped | Response Summary
Age | 21 | 0 | 18 - 24 (5), 25 - 39 (8), 40 - 55 (6), 56 - 65 (2)
Level of Hearing Loss | 21 | 0 | Mild (3), Moderate (6), Severe (5), Profound (7)
Speech Difficulty | 21 | 0 | Yes (12), No (7), Prefer not to say (2)
Use of Assistive Devices | 21 | 0 | Yes (14), No (7)
Devices Currently Used (open-ended) | 14 | 7 | Smartphone apps (5), Pen and paper (3), Picture boards (2), Text-to-speech devices (4)
Usefulness of Current Device (1â€“10) | 14 | 7 | 1 - 3 (2), 4 - 6 (5), 7 - 8 (5), 9 - 10 (2)
Openness to New Device (1â€“10) | 7 | 14 | Ratings: 3 (1), 6 (1), 7 (1), 8 (2), 9 (2)
Interest in AUSIGN | 21 | 0 | Yes (13), No (8)
Reasons for Not Interested (open-ended) | 8 | 13 | Concerns: Grammar/context issues, facial expressions not captured, regional sign variation
Suggested Extra Features (open-ended) | 17 | 4 | Bi-directional translation, context awareness, Bluetooth, haptic feedback, rechargeable battery
Reasonable Price Range | 21 | 0 | <$50 (2), $50 - 100 (6), $100 - 200 (10), >$200 (3)
Age |  |  | Level of Hearing Loss |  | Speech Difficulty |  | Use of Assistive Devices |  | Devices |  | Usefulness of Current Device
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

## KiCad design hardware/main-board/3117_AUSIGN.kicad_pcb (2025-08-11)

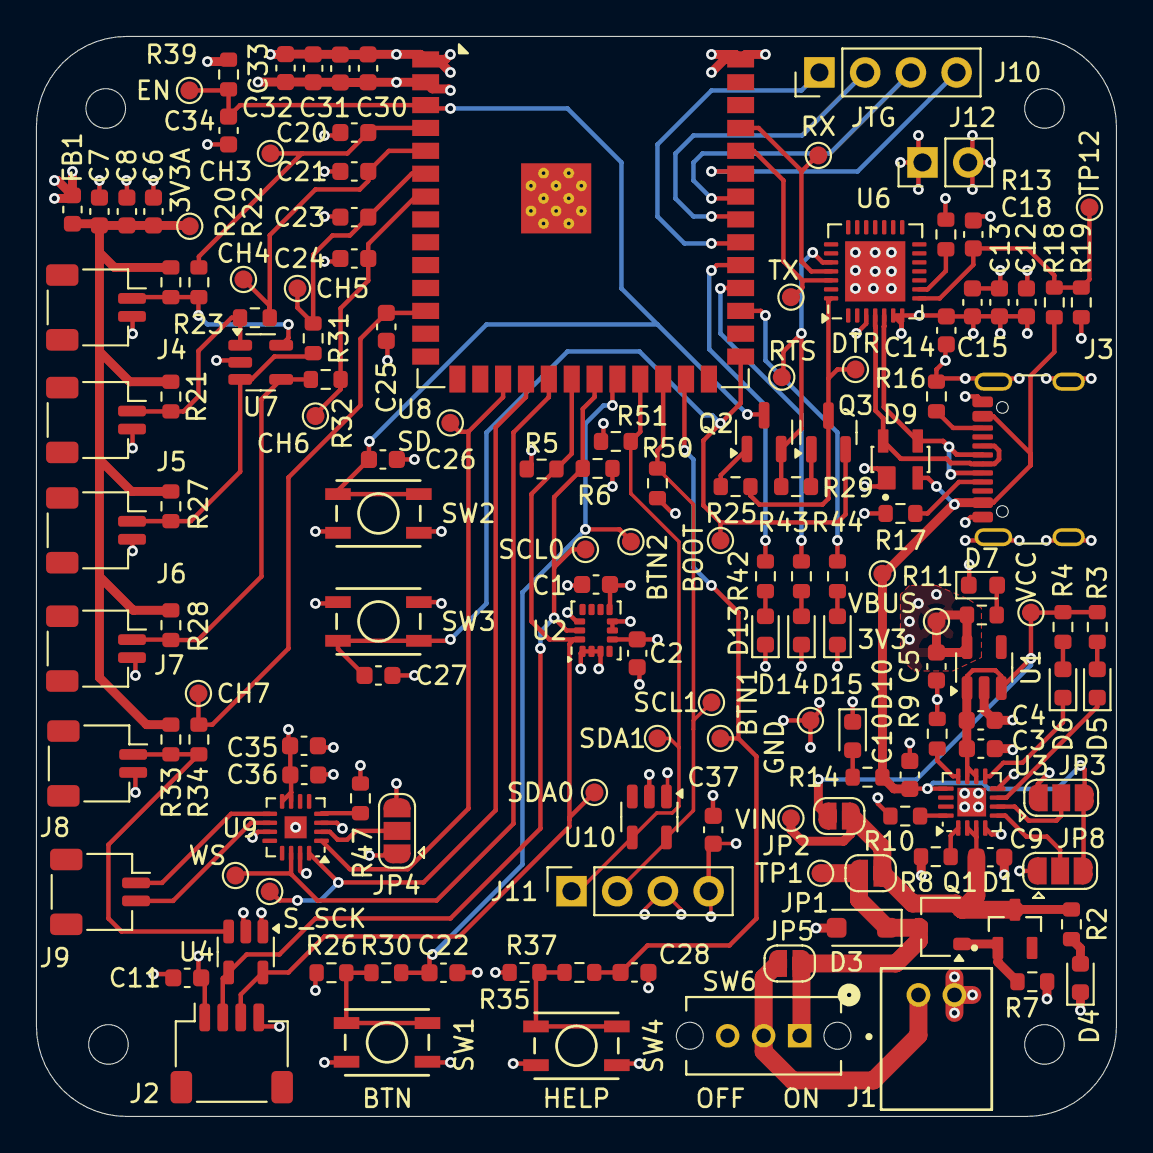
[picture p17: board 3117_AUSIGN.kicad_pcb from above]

Board: 4 copper layers, 60.0 x 60.0 mm, 151 parts (0 on the bottom side), 70 nets.

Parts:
3V3, 3V3A: TestPoint; TestPoint_Pad_D1.0mm
BOOT: TestPoint; TestPoint_Pad_D1.0mm
BTN1, BTN2: TestPoint; TestPoint_Pad_D1.0mm
C1, C2, C7, C8, C11, C14, C15, C20, C21, C22, C23, C24, C25, C26, C27, C28, C30, C31, C36, C37: 100n; C_0603_1608Metric
C3, C9, C12, C13: 4u7; C_0603_1608Metric
C4, C5, C10, C18, C34: 1u; C_0603_1608Metric
C6, C35: 10u; C_0603_1608Metric
C32, C33: 22u; C_0603_1608Metric
CH3, CH4, CH5, CH6, CH7: TestPoint; TestPoint_Pad_D1.0mm
D1: MMBZ5233BLT1G
D3: SMF5.0A; D_SOD-123F
D4, D7, D10: LTST-C190KGKT; LED_0603_1608Metric
D5, D6, D13, D14, D15: LTST-C190KFKT; LED_0603_1608Metric
D9: SP0503BAHT; SP0503BAHTG
DTR: TestPoint; TestPoint_Pad_D1.0mm
EN: TestPoint; TestPoint_Pad_D1.0mm
FB1: BLM18AG601SN1D; L_0603_1608Metric
GND: TestPoint; TestPoint_Pad_D1.0mm
H1, H2, H3, H4: MountingHole; MountingHole_2.2mm_M2
J1: JST_PH_2P
J2: JST_SH_4P; JST_SH_SM04B-SRSS-TB_1x04-1MP_P1.00mm_Horizontal
J3: USB4105-GF-A; USB_C_Receptacle_GCT_USB4105-xx-A_16P_TopMnt_Horizontal
J4, J5, J6, J7, J8, J9: JST_SH_2P; JST_SH_SM02B-SRSS-TB_1x02-1MP_P1.00mm_Horizontal
J10: Conn_01x04_Pin; PinHeader_1x04_P2.54mm_Vertical
J11: Conn_01x04_Socket; PinSocket_1x04_P2.54mm_Vertical
J12: Conn_01x02_Pin; PinHeader_1x02_P2.54mm_Vertical
JP1, JP2, JP5: SolderJumper_2_Open; SolderJumper-2_P1.3mm_Open_RoundedPad1.0x1.5mm
JP3, JP4, JP8: SolderJumper_3_Open; SolderJumper-3_P1.3mm_Open_RoundedPad1.0x1.5mm
Q1: IRLML6402TRPBF; SOT-23W
Q2, Q3: SS8050; SOT-23
R2, R3, R4: 499; R_0603_1608Metric
R5, R6, R50, R51: 4k7; R_0603_1608Metric
R7: 100k; R_0603_1608Metric
R8, R20, R21, R22, R23, R25, R26, R27, R28, R29, R31, R32, R33, R34, R35, R39: 10k; R_0603_1608Metric
R9, R10: 1.5k; R_0603_1608Metric
R11, R42, R43, R44: 200; R_0603_1608Metric
R13, R14, R30, R37: 1k; R_0603_1608Metric
R16, R17: 5k1; R_0603_1608Metric
R18: 22k1; R_0603_1608Metric
R19: 47k5; R_0603_1608Metric
R47: 634k; R_0603_1608Metric
RTS: TestPoint; TestPoint_Pad_D1.0mm
RX: TestPoint; TestPoint_Pad_D1.0mm
SCL0, SCL1: TestPoint; TestPoint_Pad_D1.0mm
SD: TestPoint; TestPoint_Pad_D1.0mm
SDA0, SDA1: TestPoint; TestPoint_Pad_D1.0mm
SW1, SW2, SW3, SW4: PTS815SJK250SMTR
SW6: OS102011MS2QN1
S_SCK: TestPoint; TestPoint_Pad_D1.0mm
TP1, TP12: TestPoint; TestPoint_Pad_D1.0mm
TX: TestPoint; TestPoint_Pad_D1.0mm
U1: AP2112K-3.3; SOT-23-5
U2: LSM6DSOTR; LGA-14_3x2.5mm_P0.5mm_LayoutBorder3x4y
U3: BQ24074RGT; VQFN-16-1EP_3x3mm_P0.5mm_EP1.6x1.6mm
U4, U7, U10: ESDS314DBVR; SOT-23-5
U6: CP2102N-A02-GQFN28; QFN-28-1EP_5x5mm_P0.5mm_EP3.35x3.35mm
U8: ESP32-S3-WROOM-1
U9: MAX98357A; TQFN-16-1EP_3x3mm_P0.5mm_EP1.23x1.23mm
VBUS: TestPoint; TestPoint_Pad_D1.0mm
VCC: TestPoint; TestPoint_Pad_D1.0mm
VIN: TestPoint; TestPoint_Pad_D1.0mm
WS: TestPoint; TestPoint_Pad_D1.0mm

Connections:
+3V3: 3V3.1, C1.1, C2.1, C5.1, C11.1, C12.1, C13.1, C14.1, C15.1, C30.1, C31.1, C32.1, C33.1, C35.1, C36.1, C37.1, FB1.1, J2.1, J11.4, J12.1, JP4.3 (B), R5.1, R6.1, R11.1, R13.1, R26.1, R35.1, R39.1, R47.1, R50.2, R51.2, U1.5 (VOUT), U2.5 (VDDIO), U2.8 (VDD), U2.12 (CS), U4.1 (I/O1), U6.6 (VDD), U6.7 (VREGIN), U8.2 (3V3), U9.7 (VDD), U9.8 (VDD), U10.1 (I/O1)
+3V3A: 3V3A.1, C6.1, C7.1, C8.1, FB1.2, R20.1, R21.1, R27.1, R28.1, R33.1
ADC1_CH3: C20.1, CH3.1, R22.1, U8.4 (IO4)
ADC1_CH4: C21.1, CH4.1, R23.1, U8.5 (IO5)
ADC1_CH5: C23.1, CH5.1, R31.1, U8.6 (IO6)
ADC1_CH6: C24.1, CH6.1, R32.1, U8.7 (IO7)
ADC1_CH7: C25.1, CH7.1, R34.1, U8.12 (IO8)
BOOT: BOOT.1, C27.1, Q3.2 (E), SW3.2 (B), U8.27 (IO0)
BTN1: BTN1.1, C28.1, R37.1, U8.25 (IO48)
BTN2: BTN2.1, C22.1, R30.1, U8.22 (IO14)
CH3: J4.1, R20.2, R22.2, U7.5 (I/O4)
CH4: J5.1, R21.2, R23.2, U7.1 (I/O1)
CH5: J6.1, R27.2, R31.2, U7.3 (I/O2)
CH6: J7.1, R28.2, R32.2, U7.4 (I/O3)
CH7: J8.1, R33.2, R34.2, U4.3 (I/O2)
DTR: DTR.1, Q3.3 (C), R25.1, U6.28 (~DTR)
EN: C26.1, C34.1, EN.1, Q2.3 (C), R39.2, SW2.2 (B), U8.3 (EN)
GND: C1.2, C2.2, C3.2, C4.2, C5.2, C6.2, C7.2, C8.2, C9.2, C10.2, C11.2, C12.2, C13.2, C14.2, C15.2, C18.2, C20.2, C21.2, C22.2, C23.2, C24.2, C25.2, C26.2, C27.2, C28.2, C30.2, C31.2, C32.2, C33.2, C34.2, C35.2, C36.2, C37.2, D3.2 (A), D4.1 (K), D7.1 (K), D9.1 (A), D10.1 (K), D13.1 (K), D14.1 (K), D15.1 (K), GND.1, J1.2, J2.4, J3.A1 (GND), J3.A12 (GND), J3.B1 (GND), J3.B12 (GND), J3.S1 (SHIELD), J4.2, J5.2, J6.2, J7.2, J8.2, J11.3, J12.2, JP3.1 (A), JP4.1 (A), JP8.1 (A), R7.2, R8.2, R9.2, R10.2, R16.2, R17.2, R19.2, SW1.1 (A), SW2.1 (A), SW3.1 (A), SW4.1 (A), U1.2 (GND), U2.1 (SDO/SA0), U2.2 (SDX), U2.3 (SCX), U2.6 (GND), U2.7 (GND), U3.4 (~CE), U3.8 (VSS), U3.17 (VSS), U4.2 (GND), U6.3 (GND), U6.29 (GND), U7.2 (GND), U8.1 (GND), U8.40 (GND), U8.41 (GND), U9.3 (GND), U9.11 (GND), U9.15 (GND), U9.17 (PAD), U10.2 (GND)
I2C0_SCL: J2.2, R6.2, SCL0.1, U2.13 (SCL), U4.4 (I/O3), U8.21 (IO13)
I2C0_SDA: J2.3, R5.2, SDA0.1, U2.14 (SDA), U4.5 (I/O4), U8.20 (IO12)
I2C1_SCL: J11.2, R50.1, SCL1.1, U8.24 (IO47), U10.5 (I/O4)
I2C1_SDA: J11.1, R51.1, SDA1.1, U8.23 (IO21), U10.4 (I/O3)
I2S_SCK: S_SCK.1, U8.18 (IO10), U9.16 (BCLK)
I2S_SD: SD.1, U8.17 (IO9), U9.1 (DIN)
I2S_WS: U8.19 (IO11), U9.14 (LRCLK), WS.1
LED3: R42.1, U8.31 (IO38)
LED4: R43.1, U8.30 (IO37)
LED5: R44.1, U8.29 (IO36)
unnamed: D1.1 (A), Q1.1 (G), R7.1
unnamed: D3.1 (K), JP1.1 (A), JP5.2 (B), Q1.3 (D), SW6.1 (A), TP1.1
unnamed: D4.2 (A), R2.2
unnamed: D5.2 (A), R3.2
unnamed: D5.1 (K), U3.7 (~PGOOD)
unnamed: D6.2 (A), R4.2
unnamed: D6.1 (K), U3.9 (~CHG)
unnamed: D7.2 (A), R11.2
unnamed: D10.2 (A), R14.2
unnamed: D13.2 (A), R42.2
unnamed: D14.2 (A), R43.2
unnamed: D15.2 (A), R44.2
unnamed: J1.1, JP5.1 (A), SW6.2 (B)
unnamed: J3.A5 (CC1), R17.1
unnamed: J3.B5 (CC2), R16.1
unnamed: J9.1, U9.9 (OUTP)
unnamed: J9.2, U9.10 (OUTN)
unnamed: JP3.2 (C), U3.6 (EN1)
unnamed: JP4.2 (C), U9.2 (GAIN_SLOT)
unnamed: JP8.2 (C), U3.5 (EN2)
unnamed: Q2.1 (B), R25.2
unnamed: Q3.1 (B), R29.2
unnamed: R26.2, R30.2, SW1.2 (B)
unnamed: R35.2, R37.2, SW4.2 (B)
unnamed: R9.1, U3.12 (ILIM)
unnamed: R10.1, U3.16 (ISET)
unnamed: R8.1, U3.1 (TS)
unnamed: C18.1, R18.2, R19.1, TP12.1, U6.8 (VBUS)
unnamed: R13.2, U6.9 (~RST)
unnamed: R47.2, U9.4 (~SD_MODE)
RTS: Q2.2 (E), R29.1, RTS.1, U6.24 (~RTS)
RXD0: RX.1, U6.25 (RXD), U8.37 (TXD0)
TCK: J10.1, U8.32 (IO39)
TDI: J10.3, U8.34 (IO41)
TDO: J10.2, U8.33 (IO40)
TMS: J10.4, U8.35 (IO42)
TXD0: TX.1, U6.26 (TXD), U8.36 (RXD0)
USB_DN: D9.3 (K), J3.A7 (D-), J3.B7 (D-), U6.5 (D-)
USB_DP: D9.4 (K), J3.A6 (D+), J3.B6 (D+), U6.4 (D+)
VBUS: C10.1, D9.2 (K), J3.A4 (VBUS), J3.A9 (VBUS), J3.B4 (VBUS), J3.B9 (VBUS), JP3.3 (B), JP8.3 (B), R14.1, R18.1, U3.13 (IN), VBUS.1
VCC: C3.1, C4.1, JP2.2 (B), R3.1, R4.1, U1.1 (VIN), U1.3 (EN), U3.10 (OUT), U3.11 (OUT), VCC.1
Vin: C9.1, D1.3 (K), JP1.2 (B), JP2.1 (A), Q1.2 (S), R2.1, U3.2 (BAT), U3.3 (BAT), VIN.1

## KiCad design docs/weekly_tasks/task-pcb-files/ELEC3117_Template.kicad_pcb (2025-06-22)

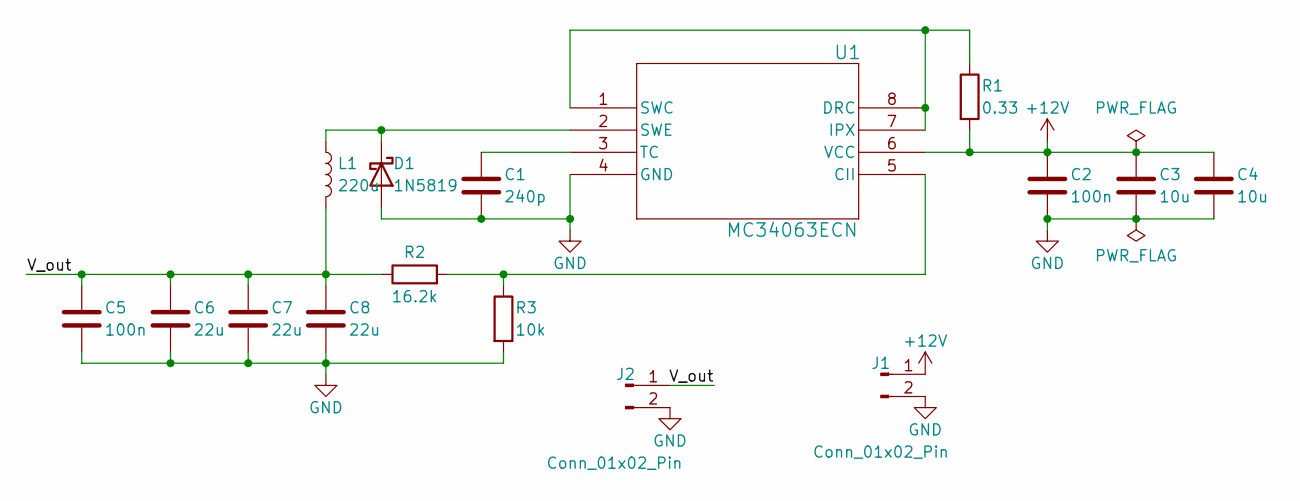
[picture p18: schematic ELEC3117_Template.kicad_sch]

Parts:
C1: 240p; C_0805_2012Metric
C2, C5: 100n; C_0805_2012Metric
C3, C4: 10u; C_0805_2012Metric
C6, C7, C8: 22u; C_0805_2012Metric
D1: 1N5819; D_DO-41_SOD81_P10.16mm_Horizontal
J1, J2: Conn_01x02_Pin; PinHeader_1x2_2.54mm_Vertical
L1: 220u; IND_RCH8011_SUM
R1: 0.33; R_0805_2012Metric
R2: 16.2k; R_0805_2012Metric
R3: 10k; R_0805_2012Metric
U1: MC34063ECN; DIP-8_STM

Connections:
+12V: C2.1, C3.1, C4.1, J1.1, R1.2, U1.6 (VCC)
/V_out: C5.1, C6.1, C7.1, C8.1, J2.1, L1.2, R2.1
GND: C1.2, C2.2, C3.2, C4.2, C5.2, C6.2, C7.2, C8.2, D1.2 (A), J1.2, J2.2, R3.2, U1.4 (GND)
unnamed: D1.1 (K), L1.1, U1.2 (SWE)
unnamed: R2.2, R3.1, U1.5 (CII)
unnamed: R1.1, U1.1 (SWC), U1.7 (IPX), U1.8 (DRC)
unnamed: C1.1, U1.3 (TC)

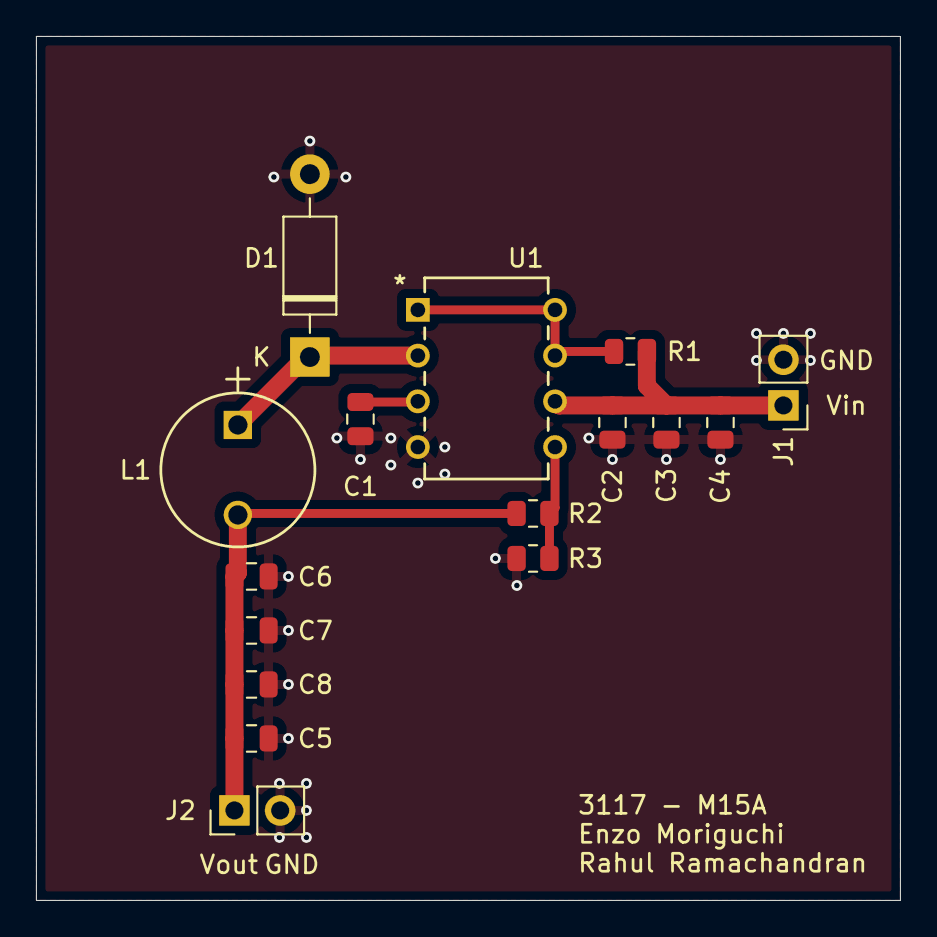
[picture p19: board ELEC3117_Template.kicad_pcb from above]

Board: 2 copper layers, 48.0 x 48.0 mm, 16 parts (0 on the bottom side), 7 nets.

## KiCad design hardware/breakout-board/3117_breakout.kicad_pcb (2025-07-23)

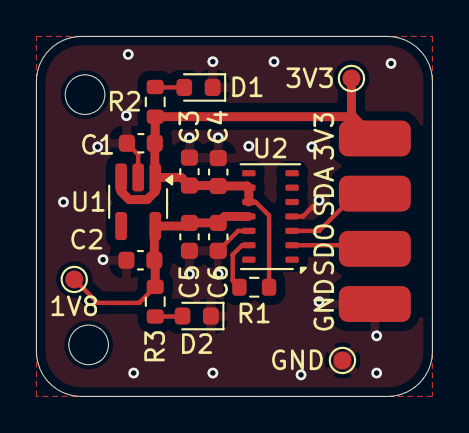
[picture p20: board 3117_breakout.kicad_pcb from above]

Board: 2 copper layers, 22.0 x 20.0 mm, 19 parts (0 on the bottom side), 8 nets.

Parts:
1V8, 3V3: TestPoint; TestPoint_Pad_D1.0mm
C1: 1u; C_0603_1608Metric
C2: 0.47u; C_0603_1608Metric
C3: 10u; C_0603_1608Metric
C4, C6: 100n; C_0603_1608Metric
C5: 4u7; C_0603_1608Metric
D1: LTST-C190KGKT; LED_0603_1608Metric
D2: 5988E40107F; LED_0603_1608Metric
GND: TestPoint; TestPoint_Pad_D1.0mm
H1, H2: MountingHole; MountingHole_2.2mm_M2
J1: Conn_01x04_Pin; JST_SH_SM04B-SRSS-TB_1x04-1MP_P1.00mm_Horizontal
R1: 4k7; R_0603_1608Metric
R2: 200; R_0603_1608Metric
R3: 49.9; R_0603_1608Metric
U1: TLV77018PDBVR; SOT-23-5_HandSoldering
U2: MAX30102; Maxim_OLGA-14_3.3x5.6mm_P0.8mm

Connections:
+1V8: 1V8.1, C2.1, C5.1, C6.1, R3.1, U1.5 (OUT), U2.11 (VDD)
+3V3: 3V3.1, C1.1, C3.1, C4.1, J1.4, R1.1, R2.1, U1.1 (IN), U1.3 (EN), U2.9 (VLED+), U2.10 (VLED+)
GND: C1.2, C2.2, C3.2, C4.2, C5.2, C6.2, D1.1 (K), D2.1 (K), GND.1, J1.1, U1.2 (GND), U2.4 (PGND), U2.12 (GND)
I2C0_SCL: J1.2, U2.2 (SCL)
I2C0_SDA: J1.3, U2.3 (SDA)
unnamed: D1.2 (A), R2.2
unnamed: D2.2 (A), R3.2
unnamed: R1.2, U2.13 (~INT)

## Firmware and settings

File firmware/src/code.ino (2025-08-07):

#include <Arduino.h>
#include <FS.h>
#include <LittleFS.h>
#include <driver/i2s.h>

// Buttons
#define HELP_PIN 48  // Both are active low
#define BTN1_PIN 14  
// I2S audio pins
#define I2S_DOUT 9
#define I2S_BCLK 10
#define I2S_LRC  11

// FLEX SENSOR definitions
#define THUMB_FLEX_SENSOR_PIN 4
#define INDEX_FLEX_SENSOR_PIN 5
#define MIDDLE_FLEX_SENSOR_PIN 6
#define RING_FLEX_SENSOR_PIN 7
#define LITTLE_FLEX_SENSOR_PIN 8

#define FLEX 1

// BLE definitions
#define SERVICE_UUID        "4fafc201-1fb5-459e-8fcc-c5c9c331914b"
#define CHARACTERISTIC_UUID "beb5483e-36e1-4688-b7f5-ea07361b26a8"

// LCD definitions
#define I2C_ADDRESS 0x3C
#define RST_PIN -1

// Includes
#include <Wire.h>
#include "MAX30105.h"
#include "heartRate.h"
#include "SSD1306Ascii.h"
#include "SSD1306AsciiWire.h"
#include "SparkFunLSM6DS3.h"
#include <BLEDevice.h>
#include <BLEUtils.h>
#include <BLEServer.h>
#include <BLE2902.h>

// Global instances
MAX30105 particleSensor;
LSM6DS3 myIMU(I2C_MODE, 0x6A);
SSD1306AsciiWire oled(Wire1);
BLECharacteristic *pCharacteristic;
bool deviceConnected = false;
String lastReceivedSign = "";
const byte RATE_SIZE = 4;
byte rates[RATE_SIZE];
byte rateSpot = 0;
long lastBeat = 0;
float beatsPerMinute;
int beatAvg;
// Priority-based audio playback
static bool helpPreviouslyPressed = false;
static bool btnPreviouslyPressed = false;

// BLE server callback
class MyServerCallbacks : public BLEServerCallbacks {
  void onConnect(BLEServer* pServer) {
    deviceConnected = true;
    Serial.println("Device connected");
  }
  void onDisconnect(BLEServer* pServer) {
    deviceConnected = false;
    Serial.println("Device disconnected");
    BLEDevice::startAdvertising();
  }
};

// BLE characteristic write callback
class MyCharacteristicCallbacks : public BLECharacteristicCallbacks {
  void onWrite(BLECharacteristic *pChar) override {
    String rxValue = pChar->getValue();
    if (rxValue.length() > 0) {
      lastReceivedSign = rxValue;
      Serial.print("Received Sign from PC: ");
      Serial.println(lastReceivedSign);
    }
  }
};

// Initialize I2S
void initI2S() {
  const i2s_config_t i2s_config = {
    .mode = (i2s_mode_t)(I2S_MODE_MASTER | I2S_MODE_TX),
    .sample_rate = 44100,
    .bits_per_sample = I2S_BITS_PER_SAMPLE_16BIT,
    .channel_format = I2S_CHANNEL_FMT_RIGHT_LEFT,
    .communication_format = I2S_COMM_FORMAT_I2S,
    .intr_alloc_flags = 0,
    .dma_buf_count = 8,
    .dma_buf_len = 64,
    .use_apll = false,
    .tx_desc_auto_clear = true,
    .fixed_mclk = 0
  };

  const i2s_pin_config_t pin_config = {
    .bck_io_num = I2S_BCLK,
    .ws_io_num = I2S_LRC,
    .data_out_num = I2S_DOUT,
    .data_in_num = I2S_PIN_NO_CHANGE
  };

  i2s_driver_install(I2S_NUM_0, &i2s_config, 0, NULL);
  i2s_set_pin(I2S_NUM_0, &pin_config);
}

// Play audio corresponding to lastReceivedSign
void playAudioFromFile(const String& name) {
  String path = "/" + name + ".raw";
  File f = LittleFS.open(path.c_str(), "r");
  if (!f) {
    Serial.print("Failed to open ");
    Serial.println(path);
    return;
  }

  Serial.print("Playing: ");
  Serial.println(path);

  uint8_t buffer[512];
  size_t bytes_written;
  while (f.available()) {
    size_t len = f.read(buffer, sizeof(buffer));
    i2s_write(I2S_NUM_0, buffer, len, &bytes_written, portMAX_DELAY);
  }

  f.close();
  Serial.println("Done playing.");
}

void setup() {
  Serial.begin(115200);
  analogReadResolution(12);
  pinMode(BTN1_PIN, INPUT_PULLUP);
  pinMode(HELP_PIN, INPUT_PULLUP);
  Wire.begin(12, 13);  // heart sensor

  // LCD
  Wire1.begin(21, 47);
  Wire1.setClock(400000L);
  oled.begin(&Adafruit128x64, I2C_ADDRESS);
  oled.setFont(Arial_bold_14);
  oled.displayRemap(true);
  oled.clear();
  oled.println("\nAuslan");

  // LittleFS
  if (!LittleFS.begin()) {
    Serial.println("LittleFS mount failed");
    while (1);
  }

  // I2S
  initI2S();

  // Heart sensor
  if (!particleSensor.begin(Wire, I2C_SPEED_FAST)) {
    Serial.println("MAX30105 not found!");
    while (1);
  }
  particleSensor.setup();
  particleSensor.setPulseAmplitudeRed(0x0A);
  particleSensor.setPulseAmplitudeGreen(0);

  // IMU
  if (myIMU.begin() != 0)
    Serial.println("IMU failed to initialize!");
  else
    Serial.println("IMU initialized.");

  // BLE
  BLEDevice::init("Auslan_glove");
  BLEServer *pServer = BLEDevice::createServer();
  pServer->setCallbacks(new MyServerCallbacks());
  BLEService *pService = pServer->createService(SERVICE_UUID);
  pCharacteristic = pService->createCharacteristic(CHARACTERISTIC_UUID,
      BLECharacteristic::PROPERTY_READ |
      BLECharacteristic::PROPERTY_WRITE |
      BLECharacteristic::PROPERTY_NOTIFY);
  pCharacteristic->addDescriptor(new BLE2902());
  pCharacteristic->setCallbacks(new MyCharacteristicCallbacks());
  pCharacteristic->setValue("Hello from ESP32");
  pService->start();
  BLEAdvertising *pAdvertising = BLEDevice::getAdvertising();
  pAdvertising->addServiceUUID(SERVICE_UUID);
  pAdvertising->setScanResponse(true);
  pAdvertising->setMinPreferred(0x06);
  pAdvertising->setMinPreferred(0x12);
  BLEDevice::startAdvertising();
  Serial.println("BLE advertising started");
}

void loop() {
  // Flex sensor
  const int numSamples = 50;
  long totals[5] = {0};
  for (int i = 0; i < numSamples; i++) {
    totals[0] += analogRead(LITTLE_FLEX_SENSOR_PIN);
    totals[1] += analogRead(RING_FLEX_SENSOR_PIN);
    totals[2] += analogRead(MIDDLE_FLEX_SENSOR_PIN);
    totals[3] += analogRead(INDEX_FLEX_SENSOR_PIN);
    totals[4] += analogRead(THUMB_FLEX_SENSOR_PIN);
    delay(2);
  }

  int avgs[5];
  for (int i = 0; i < 5; i++) avgs[i] = totals[i] / numSamples;

  Serial.print("Little:");
  Serial.print(avgs[0]);
  Serial.print(";");
  Serial.print("Ring:");
  Serial.print(avgs[1]);
  Serial.print(";");
  Serial.print("Middle:");
  Serial.print(avgs[2]);
  Serial.print(";");
  Serial.print("Index:");
  Serial.print(avgs[3]);
  Serial.print(";");
  Serial.print("Thumb:");
  Serial.println(avgs[4]);

  bool flex[5] = {
    avgs[0] > 3500, avgs[1] > 3500, avgs[2] > 3400,
    avgs[3] > 3600, avgs[4] > 3500
  };

  uint8_t flex_byte = 0;
  for (int i = 0; i < 5; i++) flex_byte |= (flex[i] << i);

  // Heartbeat
  uint8_t heartbeat_high = 0;
  long irValue = particleSensor.getIR();
  if (checkForBeat(irValue)) {
    long delta = millis() - lastBeat;
    lastBeat = millis();
    beatsPerMinute = 60 / (delta / 1000.0);
    if (beatsPerMinute > 20 && beatsPerMinute < 255) {
      rates[rateSpot++] = (byte)beatsPerMinute;
      rateSpot %= RATE_SIZE;
      beatAvg = 0;
      for (byte i = 0; i < RATE_SIZE; i++) beatAvg += rates[i];
      beatAvg /= RATE_SIZE;
    }
  }
  if (beatsPerMinute > 100) heartbeat_high = 1;

  // IMU
  int16_t ax = myIMU.readFloatAccelX() * 1000;
  int16_t ay = myIMU.readFloatAccelY() * 1000;
  int16_t az = myIMU.readFloatAccelZ() * 1000;

  // BLE send
  uint8_t payload[8];
  memcpy(payload, &ax, 2);
  memcpy(payload + 2, &ay, 2);
  memcpy(payload + 4, &az, 2);
  payload[6] = flex_byte;
  payload[7] = heartbeat_high;

  if (deviceConnected) {
    pCharacteristic->setValue(payload, 8);
    pCharacteristic->notify();
  }

  // 1. Highest priority: HELP
  if (digitalRead(HELP_PIN) == LOW && !helpPreviouslyPressed) {
    helpPreviouslyPressed = true;
    Serial.println("HELP pressed!");
    oled.clear();
    oled.println("HELP!");
    playAudioFromFile("help");  // Plays /help.raw
  } else if (digitalRead(HELP_PIN) == HIGH && helpPreviouslyPressed) {
    helpPreviouslyPressed = false;
  }

  // 2. Medium priority: BUTTON (only if HELP not pressed)
  else if (digitalRead(BTN1_PIN) == LOW && !btnPreviouslyPressed) {
    btnPreviouslyPressed = true;
    Serial.println("Button pressed!");
    oled.clear();
    oled.println("I am deaf");
    playAudioFromFile("button");  // Plays /button.raw
  } else if (digitalRead(BTN1_PIN) == HIGH && btnPreviouslyPressed) {
    btnPreviouslyPressed = false;
  }

  // 3. Lowest priority: BLE sign playback (only if no buttons pressed)
  else if (lastReceivedSign.length() > 0 && 
          digitalRead(HELP_PIN) == HIGH && 
          digitalRead(BTN1_PIN) == HIGH) {
    Serial.print("ESP32 Displayed Sign: ");
    Serial.println(lastReceivedSign);
    oled.clear();
    oled.println();
    oled.println(lastReceivedSign);
    playAudioFromFile(lastReceivedSign);  // Play .raw audio
    lastReceivedSign = "";
  }
  delay(100);
}

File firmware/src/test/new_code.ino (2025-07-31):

// FLEX SENSOR definitions
#define THUMB_FLEX_SENSOR_PIN 4
#define INDEX_FLEX_SENSOR_PIN 5
#define MIDDLE_FLEX_SENSOR_PIN 6
#define RING_FLEX_SENSOR_PIN 7
#define LITTLE_FLEX_SENSOR_PIN 8

#define FLEX 1

// Bluetooth definitons
#define SERVICE_UUID        "4fafc201-1fb5-459e-8fcc-c5c9c331914b"
#define CHARACTERISTIC_UUID "beb5483e-36e1-4688-b7f5-ea07361b26a8"

// LCD defines
// 0X3C+SA0 - 0x3C or 0x3D
#define I2C_ADDRESS 0x3C

// Define proper RST_PIN if required.
#define RST_PIN -1

// HEART RATE includes
#include <Wire.h>
#include "MAX30105.h"
#include "heartRate.h"
#include <SPI.h>

// IMU SENSOR includes
#include "SparkFunLSM6DS3.h"
#include "SPI.h"

// BLUETOOTH includes
#include <BLEDevice.h>
#include <BLEUtils.h>
#include <BLEServer.h>
#include <BLE2902.h>

// LCD includes
#include "SSD1306Ascii.h"
#include "SSD1306AsciiWire.h"

MAX30105 particleSensor;
const byte RATE_SIZE = 4;
byte rates[RATE_SIZE];
byte rateSpot = 0;
long lastBeat = 0;

float beatsPerMinute;
int beatAvg;

LSM6DS3 myIMU(I2C_MODE, 0x6A); // I2C, addr 0x6A

BLECharacteristic *pCharacteristic;
bool deviceConnected = false;
String lastReceivedSign = "";

// LCD variables
TwoWire I2C1 = TwoWire(1);

SSD1306AsciiWire oled;

// BLE server callbacks
class MyServerCallbacks : public BLEServerCallbacks {
  void onConnect(BLEServer* pServer) {
    deviceConnected = true;
    Serial.println("Device connected");
  }
  void onDisconnect(BLEServer* pServer) {
    deviceConnected = false;
    Serial.println("Device disconnected");
    BLEDevice::startAdvertising();
  }
};

// BLE write callback (receives detected sign from PC)
class MyCharacteristicCallbacks : public BLECharacteristicCallbacks {
  void onWrite(BLECharacteristic *pChar) override {
    String rxValue = pChar->getValue();
    if (rxValue.length() > 0) {
      lastReceivedSign = rxValue;
      Serial.print("Received Sign from PC: ");
      Serial.println(lastReceivedSign);
    }
  }
};

void setup() {
  Serial.begin(115200);
  analogReadResolution(12);
  
  // LCD CODE
  I2C1.begin(21,47);
  I2C1.setClock(400000L);

  #if RST_PIN >= 0
    oled.begin(&Adafruit128x64, I2C_ADDRESS, RST_PIN);
  #else // RST_PIN >= 0
    oled.begin(&Adafruit128x64, I2C_ADDRESS);
  #endif // RST_PIN >= 0

  oled.setFont(Adafruit5x7);

  uint32_t m = micros();
  oled.clear();
  oled.println("Auslan Glove");

  Wire.begin(12, 13);  // SDA, SCL
  // HEART RATE INIT
  if (!particleSensor.begin(Wire, I2C_SPEED_FAST)) {
    Serial.println("MAX30105 not found!");
    while (1);
  }
  particleSensor.setup();
  particleSensor.setPulseAmplitudeRed(0x0A);
  particleSensor.setPulseAmplitudeGreen(0);

  // IMU INIT
  if (myIMU.begin() != 0) {
    Serial.println("IMU failed to initialize!");
  } else {
    Serial.println("IMU initialized.");
  }

  // BLE INIT
  BLEDevice::init("Auslan_glove");
  BLEServer *pServer = BLEDevice::createServer();
  pServer->setCallbacks(new MyServerCallbacks());

  BLEService *pService = pServer->createService(SERVICE_UUID);
  pCharacteristic = pService->createCharacteristic(
    CHARACTERISTIC_UUID,
    BLECharacteristic::PROPERTY_READ |
    BLECharacteristic::PROPERTY_WRITE |
    BLECharacteristic::PROPERTY_NOTIFY
  );
  pCharacteristic->addDescriptor(new BLE2902());
  pCharacteristic->setCallbacks(new MyCharacteristicCallbacks());
  pCharacteristic->setValue("Hello from ESP32");

  pService->start();

  BLEAdvertising *pAdvertising = BLEDevice::getAdvertising();
  pAdvertising->addServiceUUID(SERVICE_UUID);
  pAdvertising->setScanResponse(true);
  pAdvertising->setMinPreferred(0x06);
  pAdvertising->setMinPreferred(0x12);
  BLEDevice::startAdvertising();

  Serial.println("BLE advertising started");
}

void loop() {
  // --- FLEX SENSOR ---
  const int numSamples = 50;
  long thumb_total = 0, index_total = 0, middle_total = 0, ring_total = 0, little_total = 0;

  for (int i = 0; i < numSamples; i++) {
    thumb_total += analogRead(THUMB_FLEX_SENSOR_PIN);
    index_total += analogRead(INDEX_FLEX_SENSOR_PIN);
    middle_total += analogRead(MIDDLE_FLEX_SENSOR_PIN);
    ring_total += analogRead(RING_FLEX_SENSOR_PIN);
    little_total += analogRead(LITTLE_FLEX_SENSOR_PIN);
    delay(2);
  }

  int thumb_avg = thumb_total / numSamples;
  int index_avg = index_total / numSamples;
  int middle_avg = middle_total / numSamples;
  int ring_avg = ring_total / numSamples;
  int little_avg = little_total / numSamples;

  bool thumb = thumb_avg > 3300;
  bool index = index_avg > 3300;
  bool middle = middle_avg > 3200;
  bool ring = ring_avg > 3200;
  bool little = little_avg > 3000;

  uint8_t flex_byte = 0;
  flex_byte |= (little << 0);
  flex_byte |= (ring << 1);
  flex_byte |= (middle << 2);
  flex_byte |= (index << 3);
  flex_byte |= (thumb << 4);

  // --- HEART RATE ---
  uint8_t heartbeat_high = 0;
  long irValue = particleSensor.getIR();

  if (checkForBeat(irValue)) {
    long delta = millis() - lastBeat;
    lastBeat = millis();
    beatsPerMinute = 60 / (delta / 1000.0);

    if (beatsPerMinute < 255 && beatsPerMinute > 20) {
      rates[rateSpot++] = (byte)beatsPerMinute;
      rateSpot %= RATE_SIZE;

      beatAvg = 0;
      for (byte i = 0; i < RATE_SIZE; i++) beatAvg += rates[i];
      beatAvg /= RATE_SIZE;
    }
  }
  if (beatsPerMinute > 100) heartbeat_high = 1;

  // --- IMU ---
  float ax_f = myIMU.readFloatAccelX();
  float ay_f = myIMU.readFloatAccelY();
  float az_f = myIMU.readFloatAccelZ();

  int16_t ax = (int16_t)(ax_f * 1000.0);
  int16_t ay = (int16_t)(ay_f * 1000.0);
  int16_t az = (int16_t)(az_f * 1000.0);

  // --- BLUETOOTH SEND ---
  uint8_t payload[8];
  memcpy(payload, &ax, 2);
  memcpy(payload + 2, &ay, 2);
  memcpy(payload + 4, &az, 2);
  payload[6] = flex_byte;
  payload[7] = heartbeat_high;

  if (deviceConnected) {
    pCharacteristic->setValue(payload, 8);
    pCharacteristic->notify();
  }

  // --- RECEIVED SIGN DISPLAY ---
  if (lastReceivedSign.length() > 0) {
    Serial.print("ESP32 Displayed Sign: ");
    Serial.println(lastReceivedSign);
    lastReceivedSign = "";
  }

  delay(100);
}

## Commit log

2025-06-03 added survey results
    [survey_results.xlsx]
2025-06-05 added intial hld - incomplete, does not have power supply
2025-06-05 added High Level Design and components chosen - still does not include power supply
2025-06-22 added power supply pcb report for reference
2025-06-22 created folder for pcb files ref
2025-06-22 created pcb folder
2025-06-22 added inital pcb files
    [3117_AUSIGN.kicad_pcb, 3117_AUSIGN.kicad_sch]
2025-07-02 added pitch presentation
2025-07-02 improved pitch
2025-07-03 updated financial plain in pitch
2025-07-10 code for flex sensor added - uses 50 sample average
2025-07-15 added code for scanning i2c devices and heart rate sensor
2025-07-15 four flex sensors along thumb, index, middle and ring finger adc input code added
2025-07-17 code was modified for esp32 wroom as well
2025-07-21 imu code added
2025-07-23 added main-board pcb files
    [3117_AUSIGN.kicad_pcb, 3117_AUSIGN.kicad_sch]
2025-07-23 added breakout-board pcb files
    [3117_breakout.kicad_pcb, 3117_breakout.kicad_sch]
2025-07-29 receives all sensor values onto pc
2025-07-30 play certain sounds when finger bends
2025-07-30 glove receives ble signal as well, need to fix audio now
    [code.ino, new_code.ino]
2025-07-31 lcd replaced by lightweight code
    [code.ino, lcd_screen.ino, new_code.ino]
2025-07-31 lcd code works if different i2c instance used
2025-07-31 at last lcd works in hand with all other sensors, displays sign received as well
2025-07-31 fixed text orientation and size
    [code.ino]
2025-07-31 uploaded some wav files to esp32 via littlefs and code to test audio added - havent verified whether speakers works yet
2025-08-01 python code to generate pcm raw files added also code for esp32 to play pcm files - not fully working yet
2025-08-01 memory partitioned to include more for little fs, python code ouputs raw PCM and arduino code can play it on speaker clearly - tested
    [custom_3MBAPP_9MBLFS_16MB.csv]
2025-08-01 better flex values and audio
    [code.ino]
2025-08-01 frontend added with mute button
2025-08-02 new frontend with symbols moved to different files - flex values not reliable rn
    [signs.csv]
2025-08-03 more symbols with wav files added and uploaded to esp32 memory, but flex sensors need to be fixed
    [code.ino]
2025-08-04 added code in esp to debug easier for flex; updated frontend to only send signal back if received at least 3 times - avoids incorrect gestures when changing hand signs
    [code.ino]
2025-08-06 couple sentences work now
    [sign_definitions.csv]
2025-08-06 imports from csv now
    [sign_definitions.csv]
2025-08-06 added exe file
    [sign_definitions.csv]
2025-08-07 final code changes - cleaned up code
    [sign_definitions.csv]
2025-08-11 cleaned up structure
    [3117_AUSIGN.kicad_pcb, 3117_AUSIGN.kicad_sch, 3117_breakout.kicad_pcb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]
2025-08-11 cleaned up schematic
    [3117_AUSIGN.kicad_pcb, 3117_AUSIGN.kicad_sch]
